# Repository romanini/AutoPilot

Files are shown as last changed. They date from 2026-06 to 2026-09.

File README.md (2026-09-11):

# AutoPilot Project

A DIY autopilot that steers a wheel-driven sailboat.  It holds either a
**compass heading** or **navigates to a GPS waypoint**, driving a motor on the
steering wheel. Two standalone sensors — rudder angle and masthead wind — report
to it over the same Wi-Fi network.

## System overview

Every unit joins one Wi-Fi network, `SoberPilot` (`10.20.1.x`), which the
controller itself hosts:

| Part | Hardware | Role |
|---|---|---|
| **Controller** | Arduino Nano ESP32 | The brain: reads IMU + GPS, runs PID steering, drives the motor, hosts the `SoberPilot` access point, broadcasts telemetry |
| **Display unit(s)** | Arduino Nano ESP32 + 320×480 TFT | Cockpit head unit: live autopilot state on a colour LCD, five buttons for mode/heading control. Panel is an HX8357 module or a ST7365P, detected at boot |
| **Rudder sensor** | Arduino Nano ESP32 + AS5600L | Standalone board at the quadrant: reports rudder angle, which a wheel-steered boat has no other way to know |
| **Wind sensor** | Arduino Nano ESP32 + AS5600L, Hall switch, DS18B20 | Standalone masthead unit: apparent wind angle and speed, plus air temperature |
| **Wind display** | Arduino Nano ESP32 + 320×480 TFT, portrait | Second head unit on the cockpit bulkhead: the masthead wind as an analogue dial, apparent and true. Listen-only — no buttons, transmits nothing |
| **Navigator** | Raspberry Pi 5 (8 GB) + OpenCPN | Chart plotter: GPS, AIS and vector charts; the host for the plugin below. See [`navigator/README.md`](navigator/README.md) for the hardware alternatives that were evaluated |
| **OpenCPN plugin** | `autopilot_pi` (C++/wxWidgets) | Software display unit inside OpenCPN: mirrors the TFT panel on screen, sends commands, pushes active waypoints to the controller |

How the units talk to each other

The controller is the only unit anything else talks to — the sensors, the
display and the navigator never talk to each other.

## The protocol

All communication uses plain-text UDP datagrams framed `~…$`, on four pairs of
ports:

- **Telemetry** `~APDAT,…$` — controller → everyone, **broadcast UDP 8888**, ~1 Hz.
  39 fields: date/time, GPS fix, nav_enabled, mode, waypoint, heading, pitch,
  roll, stability, bearing, speed, distance, course, location, the rudder angle
  with its health flag, and the masthead wind — apparent angle/speed, the
  controller-derived true angle/speed, and air temperature, each with its own
  health flag. `controller/publish.ino` is the wire format; `AutoPilot::parse`
  is the reader.
- **Commands** `~APCMD,<cmd>$` — display or navigator → controller, **unicast
  UDP 8889**: `m1`/`m2` (mode), `n0`/`n1` (nav enable), `a±N.NN` (heading
  adjust), `w<lat>,<lon>` (set waypoint), `X` (follow stopped), `t0`/`t1`/`t2`
  (PID auto-tune abort/arm/start), `z` (centre the rudder — relayed on to the
  rudder board).
- **Rudder sensor** — `~APRUD,<angle>,<magnet_ok>$` sensor → controller on
  **UDP 8890**; `~APCMD,z$` back on **UDP 8891**.
- **Wind sensor** — `~APWND,<direction>,<speed_kn>,…$` sensor → controller on
  **UDP 8892**; `~APCMD,v$` (vane zero) and `~APCMD,k<slope>,<offset>$`
  (speed calibration) back on **UDP 8893**.
- **Reset** `~RESET,1$`.

`mode`: `0` = off, `1` = compass-hold, `2` = waypoint-navigate.

Telemetry is broadcast, so any number of displays and plugins can listen at
once; everything else is unicast. Both sensor calibrations are runtime commands
persisted in NVS, so a unit that is already up a mast never has to be reflashed.
[`firmware/Arduino/README.md`](firmware/Arduino/README.md) is the authoritative protocol
reference.

## Directories

Five top-level directories, split by where the thing runs or what it is made of.
Each has its own README with the detail — start there rather than here.

| Directory | What's in it |
|---|---|
| [`firmware/`](firmware/README.md) | Everything that runs on a microcontroller: the five Arduino sketches, the Garmin emulator and NMEA test harness, and the offline PID and wind-dial rendering experiments |
| [`navigator/`](navigator/README.md) | Everything that runs on the Raspberry Pi 5: its setup, the config files as deployed, and the `autopilot_pi` OpenCPN plugin |
| [`circuit/`](circuit/README.md) | EasyEDA exports for the seven PCBs, and how they stack into the four units |
| [`cad/`](cad/README.md) | Enclosures, one directory per unit |
| [`assets/`](assets/) | Images and diagrams used in documentation — no README, just files |

## Quick-start by component

**Firmware** — see [`firmware/Arduino/README.md`](firmware/Arduino/README.md) for pinouts,
libraries, build, and upload commands. All five sketches (controller, display,
rudder, wind, wind-display) need a matching `arduino_secrets.h`.

**Navigator** — see [`navigator/README.md`](navigator/README.md) for the
Raspberry Pi 5 build: Ubuntu 24.04, NVMe boot, Wi-Fi onto SoberPilot, and the
OpenCPN Flatpak install.

**OpenCPN plugin** — see
[`navigator/opencpn_plugin/autopilot_pi/README.md`](navigator/opencpn_plugin/autopilot_pi/README.md)
for the panel layout, build command, and send-waypoint workflow.

**Boards** — see [`circuit/README.md`](circuit/README.md) for the seven PCBs,
how they stack into the four units, and the Gerbers to send to a board house.

**Enclosures** — see [`cad/`](cad/). The [wind sensor](cad/wind/README.md) is
built and printable; the other three are placeholders.

**Testing without a boat** — [`firmware/emulator/`](firmware/emulator/README.md) stands in for the
Garmin GPSMAP 276c on the controller's NMEA UART, and carries the test harness
for the wire contract.

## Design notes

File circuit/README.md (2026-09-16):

# AutoPilot circuit boards

This directory holds the **EasyEDA exports** for every custom PCB in the
AutoPilot project. There are seven boards, one directory each:

```
circuit/                                                                     unit
├── Controller/                 The Autopilot brain          rev 2.1  ─┐
├── Controller-12-volt-power/   power + NMEA interconnect    rev 1.0  ─┘─ controller
├── Display/                    cockpit head-unit mainboard  rev 2.2  ─┐
├── Display-Button/             buttons + TFT pass-through   rev 1.0   ├─ display
├── Display-LCD/                ST7365P panel carrier        rev 1.0  ─┘
├── Sensor-Rudder/              Inticator of rudder postion  rev 1.0  ─── rudder sensor
├── Sensor-Wind/                Wind speed and direction     rev 1.0  ─── wind sensor
└── tools/                      export automation (see tools/README.md)
```

These PCBs implement the hardware described in [`../firmware/Arduino/README.md`](../firmware/Arduino/README.md):
the **controller** reads the sensors and drives the steering motor, the
**display** is the cockpit head unit with an LCD and buttons, and the **rudder**
and **wind** sensors are standalone boards that report to the controller. All
four units are built around the **Arduino Nano ESP32** and talk to each other
over the `SoberPilot` Wi-Fi network.

## Seven boards, four enclosures

The directories are flat — one per EasyEDA project — but the boards are not
independent. They stack up into **four physical units**, and only the four
units talk to each other, over Wi-Fi:

| Unit | Boards inside it | Enclosure | Interconnect | Power |
|---|---|---|---|---|
| **Controller** | [`Controller`](Controller/README.md) + [`Controller-12-volt-power`](Controller-12-volt-power/README.md) | [`cad/controller/`](../cad/controller/README.md) | 2×10 ribbon, board to board | 12 V into the power board, fused there |
| **Display** (cockpit head unit) | [`Display`](Display/README.md) + [`Display-Button`](Display-Button/README.md) + [`Display-LCD`](Display-LCD/README.md) | [`cad/display/`](../cad/display/README.md) | 2×10 ribbon mainboard→button board, then 8-pin JST-XH button board→panel | 12 V, or its own LiPo when 12 V is absent |
| **Rudder sensor** | [`Sensor-Rudder`](Sensor-Rudder/README.md) | [`cad/rudder/`](../cad/rudder/README.md) | — (single board) | 12 V into its own terminal block |
| **Wind sensor** | [`Sensor-Wind`](Sensor-Wind/README.md) | [`cad/wind/`](../cad/wind/README.md) | — (single board) | 12 V from the masthead light circuit |

So the two controller boards share one case, the three display boards share
another, and each sensor is a sealed one-board unit with nothing running to it
but a 12 V pair — which is the point of putting them on Wi-Fi rather than
wiring them back to the controller. [`Display-LCD`](Display-LCD/README.md) is
optional: it is only fitted when the ST7365P panel is used instead of an HX8357
module.

The case each unit lives in is designed in [`../cad/`](../cad/) — one directory
per unit, linked in the table above. Only the
[wind sensor](../cad/wind/README.md) is built; the other three are placeholders
that so far only record the constraints.

## What's in each folder

Every board is exported from EasyEDA with the same 13 files, produced by
[`tools/`](tools/README.md) (`npm run export`) rather than by hand. Filenames
follow `<SCH|PCB>_<board>_<type>.<ext>`. The `README.md` alongside them is the
one hand-written file in each directory; the exporter only ever adds, so a
re-export leaves it alone:

| File | What it is |
|---|---|
| `SCH_*_PNG.png` / `SCH_*_SVG.svg` | Schematic, as a quick-look image |
| `SCH_*_EasyEDA.json` | Editable schematic source (open in EasyEDA) |
| `SCH_*_Altium.schdoc` | Schematic exported for Altium Designer |
| `PCB_*_PNG.png` / `PCB_*_SVG.svg` | PCB layout, top view |
| `PCB_*_EasyEDA.json` | Editable PCB source (open in EasyEDA) |
| `PCB_*_Gerber.zip` | **Gerbers — send this to the board house to fabricate** |
| `PCB_*_DXF.dxf` | Board outline / layers as DXF (CAD, enclosures) |
| `PCB_*_OBJ.zip` | 3D model of the assembled board (.obj) |
| `PCB_*_PhotoView-Top.svg` / `*-Bottom.svg` | Photo-realistic render of the populated board |
| `PCB_*_Autorouter.dsn` | Specctra DSN for external auto-routing |

To fabricate a board, upload its `*_Gerber.zip` to a PCB house (JLCPCB, PCBWay,
OSH Park, etc.). To edit a board, import the `*_EasyEDA.json` files back into
EasyEDA. To re-export everything after a change, see
[`tools/README.md`](tools/README.md).

---

## The seven boards

Each board directory has its own README with the schematic, the PCB image, a
component table and the design notes for that board:

| # | Board | EasyEDA project | What it is |
|---|---|---|---|
| 1 | [`Controller/`](Controller/README.md) | `SM AP Controller` rev 2.1 | The autopilot brain — Nano ESP32, BNO085 IMU, GPS, CD4010 serial buffers, motor and kill-switch headers |
| 2 | [`Controller-12-volt-power/`](Controller-12-volt-power/README.md) | `SM AP Power` rev 1.0 | Passive power and NMEA interconnect — 12 V entry, Garmin feed, USB-C, two fuses, ribbon to the controller |
| 3 | [`Display/`](Display/README.md) | `SM AP Display` rev 2.2 | Head-unit mainboard — Nano ESP32, LiPo + TP5100 charger, TPS61023 boost, voltage dividers |
| 4 | [`Display-Button/`](Display-Button/README.md) | `SM Button board V2` rev 1.0 | Five cockpit buttons, illuminated power switch, SPI pass-through to the panel |
| 5 | [`Display-LCD/`](Display-LCD/README.md) | `AutoPilot LCD Carrier` v1.0 | Optional ST7365P panel carrier — 3V3 LDO, backlight FET, 40-pin FPC |
| 6 | [`Sensor-Rudder/`](Sensor-Rudder/README.md) | `SM AP Rudder Sensor` rev 1.0 | Rudder angle — Nano ESP32 + AS5600L magnetic encoder, 12 V in |
| 7 | [`Sensor-Wind/`](Sensor-Wind/README.md) | `SM AP Wind Sensor` rev 1.0 | Masthead unit — AS5600L vane, SS40AF Hall cup sensor, DS18B20 air temperature |

---

## How the boards fit together

The units talk to each other over Wi-Fi and nothing else. The controller hosts
the **SoberPilot** access point; the display, the two sensors and the navigator
(a Raspberry Pi 5 running OpenCPN) all join it as stations. Each sensor reports
on its own port and is commanded back on the next one up, while the display and
the navigator receive the telemetry broadcast and send commands to the
controller.

How the boards fit together

What is inside the controller and the display units follows below.

### Inside the controller unit

Everything from the outside world lands on the **12-volt-power** board, which
fuses it and hands it to the **controller** over one ribbon. The controller's
only outgoing connection is the motor header — the motor driver itself is a
bought part and is not one of these boards.

Inside the controller unit

### Inside the display unit

Note the power path: **12 V and USB charge the battery and nothing else.** The
LiPo is the only thing that actually powers the display board, which then feeds
the button board and the panel.

Inside the display unit

For the firmware that runs on these boards, the pin assignments, and build
instructions, see [`../firmware/Arduino/README.md`](../firmware/Arduino/README.md). For the
overall system architecture and the UDP protocol, see the
[top-level README](../README.md). For re-exporting these files from EasyEDA,
see [`tools/README.md`](tools/README.md).

---

## Review notes (open items)

From a pass over all seven schematics, checked against the firmware. Nothing
here is a short or a crossed power rail — no net on any board carries two
different rail labels. These are the things to settle before the new boards go
out, roughly in order of how much they hurt.

**Board fix — confirmed**

1. **USB `D+`/`D−` are crossed on the display mainboard.** The USB connector's
   `D−` (pin 4) goes to the CH224K's `DP` *and* to the "Arduino USB" header's
   `D+`; `D+` (pin 5) goes to `DM` and to `D−`. The controller board wires the
   same 3-pin header straight through, so the two boards contradict each other.
   Confirmed as a genuine error — being fixed in EasyEDA; this export still has
   it. Re-export once corrected.

**Firmware TODO — next revision, once the new hardware is in hand**

Deferred deliberately: a code change that wants the real board on the bench,
not a schematic change.

2. ~~**Display voltage dividers disagree with the firmware.**~~ **Fixed.**
   `display/volt_meter.ino` now uses this board's ratios, 0.1525 (10 k/1.8 k)
   on v-in and 0.5455 (10 k/12 k) on the battery, with correction factors
   calibrated against a multimeter on 2026-09-13 (1.00487 battery, 1.01333
   v-in). Closed.
3. **Nothing ever drives the LCD carrier's backlight.** `BL_PWM` runs from the
   mainboard's `D8` through the ribbon and the button board to the carrier's
   FET gate, and no code in `display/` touches `D8`. R5's 100 kΩ holds the gate
   low, so the panel lights up black. HX8357 modules hard-wire their backlight,
   which is why this has not bitten yet.

**Marginal / out of spec**

4. **The Transmit Buffer is a level shifter pointed the wrong way.** U5 has
   `VCC` = `VDD` = 5 V with 3.3 V ESP32 inputs; at `VDD` = 5 V the CD4010B needs
   `VIH` ≥ 3.5 V. It typically works at room temperature but is not guaranteed.
   The CD4010 only converts *down* — U2 (Receive) is wired correctly at
   `VDD` = 5 V, `VCC` = 3.3 V. A 74LVC part or a real NMEA driver is the fix.
5. **Indicator LEDs with no ballast.** The controller's kill-switch LED sits
   between +5 V and a saturated 2N2222 (the 1 kΩ is in the *base*), and the
   display's switch LED runs straight to the TP5100's `LED+`/`STDBY`. Both rely
   on the switch having an internal resistor.
6. **Power-switch polarity.** CN2's contacts bridge GND and the TPS61023's `EN`,
   which Adafruit's MiniBoost pulls high — so closing the switch turns the
   display *off*. Needs a normally-closed switch, or `EN` pulled down and
   switched to 5 V.

**Verify against datasheets**

7. **LCD backlight drive.** Three cathodes, each through 51 Ω, anodes on +5 V.
   That only works if each string is a single ~3.2 V LED; series strings cannot
   run from 5 V and would need a boost driver. Biggest unknown on the carrier.
8. **CH224K `CFG1` = 56 kΩ** selects a PD voltage that then lands on the
   TP5100's input through D2. The TP5100 is a 5–18 V part, so confirm both the
   CFG table and that more than 5 V is wanted here at all.
9. **USB-C `CC`.** The controller path terminates one `CC` pin with a single
   5.1 kΩ; if the receptacle brings out `CC1` and `CC2`, the cable will only
   work one way up. (The display is fine — the CH224K terminates both.)

**Housekeeping**

10. Ribbon conductors driven at one end and unconnected at the other:
    controller↔power pins 7 (USB VBUS) and 8 (Garmin alarm) into the controller,
    14 (Garmin 12 V) likewise, and 17–20 (motor rails) out of it. Running motor
    drive down the same ribbon as Garmin serial is also an EMI risk.
11. Neither Nano gets USB `VBUS` — both "Arduino USB" headers carry `D+`/`D−`
    and ground only.
12. No decoupling anywhere on the controller (neither CD4010, nor the 5 V rail);
    the display has only the CH224K's 1 µF. No reverse-polarity or transient
    protection on any 12 V input, and the masthead board has no fuse; the
    1N5817s are 20 V parts on a boat rail.
13. The GPS's `VBat` is unconnected, so it cold-starts every power-up.
14. `controller/garmin.ino`'s pin comment swaps the names of the Receive and
    Transmit buffers. The pin numbers are right.
15. The Display schematic's title block says "Sheet 1/3", but the project
    exports as a single sheet.

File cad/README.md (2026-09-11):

# Enclosures

The case each AutoPilot unit lives in, one directory per unit. Only the wind
sensor is designed and printable; the other three record what their enclosure
has to do, ready for someone to draw it.

| Unit | Enclosure | Status | Boards inside |
|---|---|---|---|
| Wind sensor | [`wind/`](wind/README.md) | **Built** — FreeCAD sources and a full assembly guide | [`circuit/Sensor-Wind/`](../circuit/Sensor-Wind/README.md) |
| Controller | [`controller/`](controller/README.md) | Placeholder | [`circuit/Controller/`](../circuit/Controller/README.md) + [`circuit/Controller-12-volt-power/`](../circuit/Controller-12-volt-power/README.md) |
| Display | [`display/`](display/README.md) | Placeholder | [`circuit/Display/`](../circuit/Display/README.md) + [`circuit/Display-Button/`](../circuit/Display-Button/README.md) + [`circuit/Display-LCD/`](../circuit/Display-LCD/README.md) |
| Rudder sensor | [`rudder/`](rudder/README.md) | Placeholder | [`circuit/Sensor-Rudder/`](../circuit/Sensor-Rudder/README.md) |

## Layout convention

Each unit directory follows the same shape:

```
<unit>/
├── README.md     what the enclosure has to do, and what goes inside
└── *.FCStd       FreeCAD documents — the editable source
```

**FreeCAD documents are the only source of truth. No STLs are kept in the
repo** — export a mesh from the `.FCStd` when you are about to print, and leave
it out of git. Anything checked in would be a stale copy of a model that has
moved on.

The [wind sensor](wind/README.md) is the worked example: it adds an
`Assembly.md` with the step-by-step build, the shopping list, and the print
settings.

## What every one of these cases has in common

- **Plastic, not metal.** Every unit is on the `SoberPilot` Wi-Fi — the
  controller hosts the network and the other three join it as stations — so no
  case may act as a shield. The controller's is the critical one: everything
  else reaches it through those walls.
- **PETG or ASA, in a light colour.** Not PLA, which creeps and sags in the sun.
  Dark filament heats enough at a masthead or in a cockpit to go soft.
- **Sealed, with the cable entry as the weak point.** These live at a masthead,
  in a cockpit and in a quadrant locker. Only the controller's box is anywhere
  dry, and a bilge is never guaranteed dry either.
- **No iron near a magnet or a compass.** The controller carries the IMU that
  *is* the boat's heading reference, and both sensors read a magnet through a
  small air gap.

The board dimensions, connector positions and mounting holes all come from the
EasyEDA exports in [`circuit/`](../circuit/README.md) — each board directory
ships a DXF and a 3D model of the assembled board for exactly this purpose.

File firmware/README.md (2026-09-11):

# Firmware

Everything that runs on a microcontroller, plus the tooling used to test it off
the boat. Five Arduino Nano ESP32 units, one sketch each, all talking over the
`SoberPilot` Wi-Fi network — see the [top-level README](../README.md) for the
protocol and how the units fit together.

## What is in here

| Directory | What it is |
|---|---|
| [`Arduino/`](Arduino/README.md) | All the sketches, the vendored libraries and the upload tooling. **Its README is the authoritative build reference** — pinouts, library table, `arduino-cli` commands |
| [`emulator/`](emulator/README.md) | A Python stand-in for the Garmin GPSMAP 276c on the controller's NMEA UART, plus the authoritative implementation of the NMEA wire contract and its tests |
| `experiments/pid/` | Offline PID tuning — `pid_test.py` replays logged runs and plots them with matplotlib |
| [`experiments/wind-display-render/`](experiments/wind-display-render/README.md) | Compiles the wind display's real drawing code on the Mac and renders PNGs of every screen state — how its layout is checked, and how the incremental repaint is proven leak-free, without hardware |

## The five units

Each sketch is one physical unit. The board it runs on and the case it lives in
are documented alongside it:

| Sketch | Unit | Board | Enclosure |
|---|---|---|---|
| [`Arduino/controller/`](Arduino/controller/) | The brain — IMU, GPS, PID steering, motor drive, and the Wi-Fi access point | [`circuit/Controller/`](../circuit/Controller/README.md) | [`cad/controller/`](../cad/controller/README.md) |
| [`Arduino/display/`](Arduino/display/) | Cockpit head unit — TFT and five buttons | [`circuit/Display/`](../circuit/Display/README.md) | [`cad/display/`](../cad/display/README.md) |
| [`Arduino/rudder/`](Arduino/rudder/) | Rudder angle sensor at the quadrant | [`circuit/Sensor-Rudder/`](../circuit/Sensor-Rudder/README.md) | [`cad/rudder/`](../cad/rudder/README.md) |
| [`Arduino/wind/`](Arduino/wind/) | Masthead wind sensor — angle, speed, air temperature | [`circuit/Sensor-Wind/`](../circuit/Sensor-Wind/README.md) | [`cad/wind/`](../cad/wind/README.md) |
| [`Arduino/wind-display/`](Arduino/wind-display/) | Cockpit wind display — portrait analogue wind dial, listen-only | [`circuit/Display/`](../circuit/Display/README.md) (same boards as the head unit) | — |

`Arduino/` also holds single-purpose sketches that are not units: `garmin/` for
bringing up the Garmin NMEA input, and `panel_detect/`, `panel_probe/` and
`st7365_bringup/` for identifying and driving the display panel.

## Before you build

Every sketch needs an `arduino_secrets.h` with the Wi-Fi password, and **it must
match across the controller, every display (including the wind display), and
both sensors** — a mismatch
looks like a unit that boots fine and never appears on the network. Copy the
example alongside each sketch to get started.

Libraries are declared in each sketch's `sketch.yaml` and in the table in
[`Arduino/README.md`](Arduino/README.md); when adding an `#include`, update
those rather than vendoring the library.

## Testing without a boat

[`emulator/`](emulator/README.md) drives the controller's Garmin UART over a
USB-serial tap, so route and waypoint handling can be exercised at a desk. It is
a serial device rather than an IP endpoint, and it is the reference
implementation of the NMEA framing the controller parses — if the two ever
disagree, the emulator's tests are the tie-breaker.

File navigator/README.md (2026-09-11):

# Navigator

The navigation computer runs Ubuntu with OpenCPN (Flatpak) and the `autopilot_pi` plugin.
Version depends on hardware: 22.04 on the OrangePi and RPi 4, 24.04 on the RPi 5 (22.04
predates Pi 5 hardware support). Hardware options evaluated so far:

| Hardware | Power @ 12 V | OpenGL | Notes |
|---|---|---|---|
| OrangePi Zero 2W | ~2.4-3.3 W (0.2-0.28 A) | Off — GPU driver unreliable | Development unit |
| Raspberry Pi 4 Model B (8 GB) | ~3.0-6.0W (0.25-0.5 A) | On — VideoCore VI (vc4-kms-v3d) works | Better chart rendering |
| Raspberry Pi 5 (8 GB) | 4.5W | On — VideoCore VII, faster than RPi 4 | SD card + NVMe (see below) |

OpenGL makes chart panning and zooming significantly faster. The RPi 4 and RPi 5 support it;
the OrangePi does not. Measure actual power draw with a meter before choosing which to install
on the boat.

**RPi 5 boot media:** the Pi 5 uses both an SD card and an NVMe drive (attached via a PCIe
M.2 HAT). NVMe is the primary boot device — faster and no SD wear-out concerns for an
appliance that's powered on/off with the boat. The SD card stays installed as a fallback: if
the NVMe drive ever fails or is removed, the bootloader falls back to booting it. Both cards
get a full, independent Ubuntu install — see [Part 1](#part-1--flash-the-boot-media-on-your-mac)
and [Enable NVMe boot](#raspberry-pi-5--enable-nvme-boot) below.

---

## SD card backup and restore

The navigator setup is not distributed as a disk image — it is too large for Git.
To set up a fresh card, follow the from-scratch setup below. Use the commands here
to back up an existing working card or restore from a backup.

**Two things make `dd` fast on macOS:**
- Use `/dev/rdisk3` not `/dev/disk3` — the `r` prefix (raw device) bypasses the buffer cache and is ~10× faster.
- Use `bs=4m` for large block transfers instead of the default 512-byte blocks.

Pipe through `gzip` to compress the output; this cuts file size roughly in half
and is usually faster overall because writing less to disk beats the CPU cost of
compression. Hit **Ctrl+T** at any time to print progress.

### Backup: SD card → compressed file

1. Find your SD card device:
   ```bash
   diskutil list
   ```
2. Unmount it (replace `disk3` with your actual device):
   ```bash
   diskutil unmountDisk /dev/disk3
   ```
3. Copy and compress (use the filename for your hardware/media):
   ```bash
   # OrangePi Zero 2W
   sudo dd if=/dev/rdisk3 bs=4m | gzip > navigator-OrangePiZero2W-$(date +%Y-%m-%d).img.gz
   # Raspberry Pi 4 Model B
   sudo dd if=/dev/rdisk3 bs=4m | gzip > navigator-RaspberryPi4ModelB-$(date +%Y-%m-%d).img.gz
   # Raspberry Pi 5 — SD card (fallback boot)
   sudo dd if=/dev/rdisk3 bs=4m | gzip > navigator-RaspberryPi5-SD-$(date +%Y-%m-%d).img.gz
   # Raspberry Pi 5 — NVMe (primary boot; remove from the M.2 HAT and attach via a
   # USB-to-M.2 NVMe enclosure — the device node will differ, check `diskutil list`)
   sudo dd if=/dev/rdisk4 bs=4m | gzip > navigator-RaspberryPi5-NVMe-$(date +%Y-%m-%d).img.gz
   ```

### Restore: compressed file → SD card

1. Unmount the card:
   ```bash
   diskutil unmountDisk /dev/disk3
   ```
2. Decompress and write:
   ```bash
   # OrangePi Zero 2W
   gunzip -c navigator-OrangePiZero2W-YYYY-MM-DD.img.gz | sudo dd of=/dev/rdisk3 bs=4m
   # Raspberry Pi 4 Model B
   gunzip -c navigator-RaspberryPi4ModelB-YYYY-MM-DD.img.gz | sudo dd of=/dev/rdisk3 bs=4m
   # Raspberry Pi 5 — SD card
   gunzip -c navigator-RaspberryPi5-SD-YYYY-MM-DD.img.gz | sudo dd of=/dev/rdisk3 bs=4m
   # Raspberry Pi 5 — NVMe (via USB-to-M.2 enclosure; check `diskutil list` for the device node)
   gunzip -c navigator-RaspberryPi5-NVMe-YYYY-MM-DD.img.gz | sudo dd of=/dev/rdisk4 bs=4m
   ```

---

## From-scratch setup

### Part 1 — Flash the boot media (on your Mac)

#### OrangePi Zero 2W

1. Go to the OrangePi Zero 2W product page at orangepi.org → **Resources** and download
   the **Ubuntu Jammy (22.04)** image.
2. Decompress the `.xz` archive:
   ```bash
   xz -d Orangepi*.img.xz
   ```
3. Unmount the SD card and flash it directly (no gzip since the image is already unpacked):
   ```bash
   diskutil unmountDisk /dev/disk2
   sudo dd if=Orangepi*.img of=/dev/rdisk2 bs=4m
   ```

#### Raspberry Pi 4 Model B

1. Install [Raspberry Pi Imager](https://www.raspberrypi.com/software/) on your Mac.
2. Open Imager → **Choose OS** → **Other general-purpose OS** → **Ubuntu** →
   **Ubuntu Server 22.04 LTS (64-bit)**.
3. Click the ⚙ settings icon and configure:
   - **Hostname:** `navigator`
   - **Username:** `navigator`
   - **Password:** your choice
   - **Enable SSH:** yes
4. **Choose Storage** → select your SD card → **Write**.

The root filesystem expands to fill the card automatically on first boot — no manual step needed.

#### Raspberry Pi 5 (SD card + NVMe)

Flash **both** cards now, before the Pi 5 ever powers on — it's easiest to do them
back-to-back on the Mac while Imager is already open.

1. **SD card first** (this becomes the fallback boot media): same steps as RPi 4 above, except
   choose **Ubuntu Server 24.04 LTS (64-bit)** and use hostname `navigator`. Set the same
   username/password/SSH settings you'll use on the NVMe drive.
2. **NVMe drive** (this becomes the primary boot media): connect the NVMe drive to your Mac
   via a USB-to-M.2 NVMe enclosure/adapter (it isn't readable directly — the Pi 5's M.2 HAT
   is the only thing that talks to it over PCIe). In Imager, repeat the same OS choice
   (**Ubuntu Server 24.04 LTS (64-bit)**) and the same ⚙ settings (hostname `navigator`,
   same username/password, SSH enabled) → **Choose Storage** → select the NVMe device (not
   the SD card!) → **Write**.
3. Don't set `BOOT_ORDER` yet — NVMe boot has to be enabled from the EEPROM bootloader while
   running from the SD card, so put the SD card in and boot that first. The NVMe drive itself
   can go into the M.2 HAT whenever it's convenient: the EEPROM only decides what the
   *bootloader* tries, so an installed drive stays inert until
   [Enable NVMe boot](#raspberry-pi-5--enable-nvme-boot) after Part 2 below.

**Don't have the NVMe drive yet?** Skip step 2 above and do everything through Post-setup on
the SD card alone — see
[Set up on the SD card now, clone to NVMe later](#set-up-on-the-sd-card-now-clone-to-nvme-later)
below for how to catch the NVMe drive up once it arrives.

#### Set up on the SD card now, clone to NVMe later

You don't need the NVMe drive in hand to get started — flash and set up the SD card only
(steps above minus step 2), work all the way through Part 2 → Post-setup on it, and validate
everything works. When the NVMe drive arrives:

1. **Back up the SD card first.** Shut down, remove the SD card, and image it on your Mac using
   the [backup commands](#backup-sd-card--compressed-file) (the
   `navigator-RaspberryPi5-SD-...img.gz` line). This is the only rollback if the clone goes
   wrong. Re-insert the SD card and boot the Pi 5 normally again.

2. **Install the NVMe drive in the M.2 HAT** — no USB-to-M.2 enclosure needed. `BOOT_ORDER`
   still points at the SD card, so the Pi keeps booting from it while the NVMe shows up as an
   ordinary block device you can clone onto locally. Boot from the SD card and confirm:

   ```bash
   lsblk -o NAME,SIZE,TYPE,FSTYPE,LABEL,LOG-SEC,MOUNTPOINTS
   ```

   Check three things: the drive is `nvme0n1` at the expected size, the live system is on
   `mmcblk0`, and `LOG-SEC` reads `512`. A namespace formatted 4Kn needs a different approach —
   the SD image's partition table uses 512-byte offsets, so a straight `dd` clone onto it would
   produce a broken layout.

   If `nvme0n1` doesn't appear at all, the PCIe port isn't enabled. The official Raspberry Pi
   M.2 HAT+ enables it automatically via its HAT EEPROM; third-party boards (Pimoroni NVMe Base,
   Geekworm, Waveshare) generally don't. Add `dtparam=pciex1` under `[all]` in
   `/boot/firmware/config.txt` and reboot.

3. **Wipe the drive if it has ever been used for anything else** (skip only for a genuinely
   factory-fresh drive — and copy off anything you still want first, all of it is destroyed
   here).

   This is not just tidiness. A drive formatted by macOS or Windows carries a **GPT**: a primary
   header at LBA 1 and a backup header in the *last sector of the drive*. Cloning a 32 GB SD
   image onto a 1 TB NVMe overwrites the primary but leaves the backup untouched, so the disk
   ends up carrying both a valid MBR and a valid backup GPT. `parted` and `gdisk` then report
   the GPT as corrupt and offer to rebuild it from the backup — which discards the MBR you just
   cloned — and `sfdisk`/`growpart` in step 5 can auto-detect the wrong label type entirely.

   ```bash
   lsblk -no MOUNTPOINTS /dev/nvme0n1   # unmount anything listed before continuing
   sudo blkdiscard -f /dev/nvme0n1      # TRIM the whole drive: seconds, vs hours to zero-fill
   sudo wipefs -a /dev/nvme0n1          # this is what kills the backup GPT
   sudo partprobe /dev/nvme0n1
   ```

   `blkdiscard` alone is not enough — not every controller guarantees discarded blocks read back
   as zeros, so `wipefs` removes the signatures explicitly rather than assuming.

4. **Quiesce the system and clone.** Dropping to `multi-user.target` stops the desktop and
   OpenCPN writing during the copy:

   ```bash
   sudo systemctl isolate multi-user.target
   sudo dd if=/dev/mmcblk0 of=/dev/nvme0n1 bs=4M status=progress conv=fsync
   sudo partprobe /dev/nvme0n1
   ```

   Cloning a mounted root filesystem means files written during the copy (in practice, logs) can
   land inconsistent; the `e2fsck` in step 5b resolves the metadata side, and this is what
   `rpi-clone` and similar tools do anyway. To write the pristine image instead, put the
   `.img.gz` from step 1 on a USB stick and
   `gunzip -c /media/…/navigator-RaspberryPi5-SD-*.img.gz | sudo dd of=/dev/nvme0n1 bs=4M status=progress`.

5. **Give the clone its own identity, and grow it into the drive.** A straight clone leaves the
   NVMe with the same MBR disk signature (and therefore `PARTUUID`s), the same filesystem UUIDs,
   **the same filesystem labels**, the same machine-id and the same SSH host keys as the SD card.
   With both physically installed at once — which is the whole point of the fallback design —
   that's not cosmetic: the kernel, udev and blkid can't reliably tell the two apart and may
   resolve to the wrong one.

   **The labels matter most, because this image boots by label.** `boot/firmware/cmdline.txt` in
   this repo has `root=LABEL=writable`, and `/etc/fstab` mounts `LABEL=writable` and
   `LABEL=system-boot`. Leave the clone's labels alone and `root=LABEL=writable` is ambiguous with
   both media installed — you can end up with a Pi that boots the NVMe's firmware but runs the SD
   card's filesystem. Relabelling the NVMe fixes both directions at once: the SD's `writable` then
   matches only the SD, and the NVMe's `writable-nvme` matches only the NVMe.

   Do all of this with the NVMe unmounted, in this order (adjust partition numbers if `lsblk`
   showed something other than `p1`/`p2`):

   a. **New MBR disk signature** — this is what each partition's `PARTUUID` is derived from
      (`<disk-id>-<partition-number>`):
      ```bash
      sudo sfdisk --disk-id /dev/nvme0n1 0x$(openssl rand -hex 4)
      sudo partprobe /dev/nvme0n1
      ```
   b. **Grow the root partition to fill the drive.** Without this a clone of a 32 GB card onto a
      1 TB drive is still a 32 GB system — cloud-init's first-boot auto-resize already ran on the
      SD card and won't run again. `growpart` comes from `cloud-guest-utils`:
      ```bash
      sudo growpart /dev/nvme0n1 2
      sudo e2fsck -f /dev/nvme0n1p2
      sudo resize2fs /dev/nvme0n1p2
      ```
   c. **New root filesystem UUID:**
      ```bash
      sudo tune2fs -U random /dev/nvme0n1p2
      ```
   d. **New labels** — see above, this is the one that decides whether it boots the right root:
      ```bash
      sudo e2label /dev/nvme0n1p2 writable-nvme
      sudo fatlabel /dev/nvme0n1p1 SYSTEM-NVME
      ```
      The FAT label must be uppercase and at most 11 characters — dosfstools 4.2 refuses lowercase
      labels, and `SYSTEM-NVME` is exactly 11. ext4 allows 16, so `writable-nvme` fits.
   e. **New FAT32 volume ID.** `dosfstools` has no in-place command for this, so patch the 4-byte
      `BS_VolID` field directly at its fixed offset (67) in the boot sector instead of
      reformatting:
      ```bash
      sudo dd if=/dev/urandom of=/dev/nvme0n1p1 bs=1 count=4 seek=67 conv=notrunc
      ```
   f. **Confirm the two media now look nothing alike:**
      ```bash
      sudo blkid /dev/mmcblk0p1 /dev/mmcblk0p2 /dev/nvme0n1p1 /dev/nvme0n1p2
      ```
      All four labels and all four UUIDs should be distinct before you go any further.

6. **Point the clone's boot config at its own labels.** Both `sed` patterns below are idempotent —
   the replacement text no longer matches the pattern, so re-running them is harmless.

   ```bash
   sudo mkdir -p /mnt/nvme-boot /mnt/nvme-root
   sudo mount /dev/nvme0n1p1 /mnt/nvme-boot
   sudo mount /dev/nvme0n1p2 /mnt/nvme-root

   sudo sed -i 's|root=LABEL=writable |root=LABEL=writable-nvme |' /mnt/nvme-boot/cmdline.txt
   sudo sed -i 's|LABEL=writable\([[:space:]]\)|LABEL=writable-nvme\1|; s|LABEL=system-boot\([[:space:]]\)|LABEL=SYSTEM-NVME\1|' /mnt/nvme-root/etc/fstab

   # Read both back — this is the step that decides whether it boots at all
   cat /mnt/nvme-boot/cmdline.txt /mnt/nvme-root/etc/fstab
   ```

   Then **machine-id and SSH host keys** — not partition-related, but the same "identical clone"
   problem: both media would otherwise claim the same machine identity on the network.

   ```bash
   sudo rm /mnt/nvme-root/etc/machine-id
   sudo systemd-machine-id-setup --root=/mnt/nvme-root
   sudo rm /mnt/nvme-root/etc/ssh/ssh_host_*
   sudo ssh-keygen -A -f /mnt/nvme-root

   # Normally a symlink to /etc/machine-id; if it's a real file, copy the new one over it
   ls -l /mnt/nvme-root/var/lib/dbus/machine-id

   sudo umount /mnt/nvme-boot /mnt/nvme-root
   ```

   Expect two harmless side effects on first NVMe boot: your Mac refuses to connect until you run
   `ssh-keygen -R navigator.local`, and the Pi may take a different DHCP lease because the
   machine-id changed.

7. Pick up at step 2 of [Enable NVMe boot](#raspberry-pi-5--enable-nvme-boot) below — the drive is
   already installed, so all that's left is the EEPROM update, `BOOT_ORDER`, and verifying it
   actually boots from `nvme0n1`.

> Nothing in steps 2–6 touches the SD card, so it stays a working system throughout. If the clone
> misbehaves, re-run steps 3–6 from scratch on the NVMe; the image from step 1 is the backstop if
> the SD card itself is ever damaged.

---

### Part 2 — First boot

Insert the SD card, connect monitor + keyboard + mouse, power on.

| Platform | Default login |
|---|---|
| OrangePi | `orangepi` / `orangepi` |
| RPi 4 | `navigator` / your choice |
| RPi 5 | `navigator` / your choice (boots from the SD card at this point) |

```bash
# OrangePi only — RPi hostname was already set in Imager
sudo hostnamectl set-hostname navigator

# Full system update
sudo apt update && sudo apt full-upgrade -y
sudo reboot
```

**RPi 5 only:** stop here and do
[Enable NVMe boot](#raspberry-pi-5--enable-nvme-boot) before continuing to Part 3 — it needs
to run while still booted from the SD card.

---

### Raspberry Pi 5 — enable NVMe boot

> Do this once, after the SD card's first boot/update/reboot above. Arriving from
> [clone to NVMe later](#set-up-on-the-sd-card-now-clone-to-nvme-later)? The drive is already
> installed — start at step 2.

1. Install the NVMe drive in the M.2 HAT and confirm the Pi sees it. Installing it before
   `BOOT_ORDER` is set is fine — the EEPROM only decides what the bootloader *tries*, so the Pi
   keeps booting from the SD card until step 3 takes effect.
   ```bash
   lsblk           # nvme0n1 should be listed
   ```
   If it isn't, the PCIe port isn't enabled: the official M.2 HAT+ does it automatically via its
   HAT EEPROM, most third-party boards don't. Add `dtparam=pciex1` under `[all]` in
   `/boot/firmware/config.txt` and reboot.
2. Update the EEPROM bootloader to the latest version (older units shipped without NVMe boot
   support):
   ```bash
   sudo apt update && sudo apt install -y rpi-eeprom
   sudo rpi-eeprom-update -a
   sudo reboot
   ```
3. After reboot, set the boot order to try NVMe first and fall back to the SD card:
   ```bash
   sudo -E rpi-eeprom-config --edit
   ```
   That opens `nano`. Set this line — replacing any existing one, don't end up with two — then
   `^X`, `Y`, and **Enter** at the "File Name to Write" prompt:
   ```
   BOOT_ORDER=0xf16
   ```
   Reading right-to-left: `6`=NVMe tried first, `1`=SD card fallback, `f`=retry the sequence
   forever rather than giving up.

   **Don't verify with `sudo rpi-eeprom-config` yet — it will still show the old value, and that
   does not mean the edit failed.** The EEPROM can only be written by the bootloader at boot, so
   `--edit` builds a new bootloader image with the config baked in and *stages* it on the boot
   partition, while plain `rpi-eeprom-config` reads back the **currently running** EEPROM. Confirm
   it was staged instead:
   ```bash
   sudo rpi-eeprom-update                                       # should report an update pending
   ls -l /boot/firmware/pieeprom.upd /boot/firmware/pieeprom.sig
   ```
   If nothing was staged, skip the editor entirely — extract the config, edit the file directly,
   and apply it:
   ```bash
   sudo rpi-eeprom-config --out /tmp/bootconf.txt
   nano /tmp/bootconf.txt
   sudo rpi-eeprom-config --apply /tmp/bootconf.txt
   ```
4. Reboot, then verify both the config and where you actually booted from:
   ```bash
   sudo reboot
   ```
   ```bash
   sudo rpi-eeprom-config      # BOOT_ORDER=0xf16 should be there now
   vcgencmd bootloader_config  # reads the live EEPROM directly, independent of the tooling
   findmnt /                   # source should be /dev/nvme0n1p2, not /dev/mmcblk0p2
   df -h /                     # should show the full NVMe capacity, not the old SD size
   lsblk                       # mmcblk0 present, but nothing mounted from it
   ```
   If it still booted from the SD card, re-check `BOOT_ORDER` and that `nvme0n1p1` actually
   contains a `config.txt`.
5. If the NVMe drive isn't detected reliably (PCIe signal integrity issues are common with longer
   ribbon cables), force Gen 3 speed by adding this to `/boot/firmware/config.txt` and rebooting:
   ```
   dtparam=pciex1_gen=3
   ```

From here on, log in and do all further setup (networking, `apt full-upgrade`, Claude Code
bootstrap) on the **NVMe-booted** system — the SD card just sits in the slot as a cold
fallback and doesn't need further updates until you actually fail over to it.

---

### Part 3 — Networking (do this manually, before Claude)

> **Do this by hand — do not let Claude do it.** Claude Code needs a live internet
> connection to the model. If Claude reconfigures the Wi-Fi adapters, it drops its own
> connection mid-command and stops. Bring networking up yourself now so Claude starts from
> an already-connected machine.

Connect both Wi-Fi networks and set route metrics so internet goes out your home network,
not SoberPilot. **Lower metric wins**, so give home the lower number. (Full rationale and
the power-save / keepalive details are in [Dual Wi-Fi networking](#dual-wi-fi-networking)
below.)

```bash
# Connect to each network. nmcli usually picks the right adapter automatically, but
# SoberPilot MUST end up on wlan0 (onboard) — the USB adapter is for home/internet only.
nmcli device wifi connect SoberPilot password <password>
nmcli device wifi connect <home-ssid> password <password> ifname <usb-adapter-ifname>

# Lock SoberPilot to wlan0 so nothing can accidentally pull it onto the USB adapter later
nmcli connection modify SoberPilot connection.interface-name wlan0

# SoberPilot = high metric (600), home internet = low metric (100)
nmcli connection modify SoberPilot ipv4.route-metric 600
nmcli connection modify "<home-network-connection-name>" ipv4.route-metric 100
nmcli connection up "<home-network-connection-name>"
nmcli connection up SoberPilot
```

Find your USB adapter's interface name with `ip link show` or `nmcli device status` (it'll be
something like `wlx0013efc00bc4` — a MAC-address-derived name, not `wlan1`). To find the
connection name nmcli assigned to the home network: `nmcli connection show`.

**Verify the default route goes out your home network:**

```bash
ip route list
```

The top `default` line must be via your **home** gateway. If SoberPilot's gateway has the
lower metric, internet traffic (and Claude) tries to route through the controller's AP,
which has no internet. Fix it:

```bash
# Immediate override — drop SoberPilot's default route.
# This keeps its subnet route, so telemetry to the controller still works.
sudo ip route del default via <soberpilot-gateway>

# Confirm
ip route list          # top default line should now be via your home gateway
ping -c2 1.1.1.1       # confirm internet
```

The `nmcli ... ipv4.route-metric` commands above make the correct ordering permanent; the
`ip route del` is just an immediate override until the next reconnect. If `ip route list`
already showed home on top, you can skip the `ip route del` step.

---

### Part 4 — Bootstrap: git and Claude Code

After reboot, log back in and run:

```bash
# Node.js 20 (Claude Code runtime) + git
curl -fsSL https://deb.nodesource.com/setup_20.x | sudo -E bash -
sudo apt-get install -y nodejs git

# Claude Code
sudo npm install -g @anthropic-ai/claude-code

# Authenticate — opens a browser window for OAuth
claude login
```

#### Generate an SSH key for GitHub

```bash
ssh-keygen -t ed25519 -C "romaninim@gmail.com"
```
Accept the default path (`~/.ssh/id_ed25519`); set a passphrase or leave it blank on a
headless box like this one.

```bash
eval "$(ssh-agent -s)"
ssh-add ~/.ssh/id_ed25519
cat ~/.ssh/id_ed25519.pub
```

Copy that public key into [github.com/settings/keys](https://github.com/settings/keys) →
**New SSH key**, then verify it:

```bash
ssh -T git@github.com   # should reply "Hi <username>! You've successfully authenticated..."
```

#### Clone this repo

```bash
mkdir -p ~/dev
git clone git@github.com:romanini/AutoPilot.git ~/dev/AutoPilot
```

---

### Part 5 — Let Claude Code complete the setup

```bash
cd ~/dev/AutoPilot
claude
```

Tell Claude Code:

> "Set up this machine as the navigator computer. Follow `navigator/README.md` exactly.
> My hardware is [OrangePi Zero 2W / Raspberry Pi 4 Model B / Raspberry Pi 5]. Networking is
> already configured — do not touch the Wi-Fi adapters, connections, or routes."

Claude Code will work through the remaining System Configuration sections below — udev
rules, systemd service, OpenCPN, and the autopilot_pi plugin. **Networking is already
done in Part 3** and Claude must leave it alone, otherwise it will lose its connection to
the model.

---

## System configuration

These are the steps Claude Code follows. You can also run them manually in order.

### NetworkManager

Both platforms use NetworkManager for Wi-Fi. On RPi Ubuntu Server it is not installed
by default.

```bash
sudo apt install -y network-manager
sudo systemctl enable --now NetworkManager
```

Update netplan to delegate to NetworkManager. The existing netplan filename varies by
platform (`orangepi-default.yaml` on OrangePi, `50-cloud-init.yaml` on RPi). Replace
its contents with:

```yaml
network:
  version: 2
  renderer: NetworkManager
```

Then apply:

```bash
sudo netplan apply
```

---

### Dual Wi-Fi networking

> Done manually in [Part 3](#part-3--networking-do-this-manually-before-claude), **not** by
> Claude — reconfiguring the adapters would drop Claude's connection to the model. This
> section is the full reference for those steps.

Two Wi-Fi adapters are required:

- **`wlan0`** (onboard) → joins **SoberPilot** (the controller's AP) on `10.20.1.x`
- **USB Wi-Fi adapter** (`wlx...`) → joins your home/internet network

**Important — USB adapter is 2.4 GHz only.** The USB adapter tested with this setup
does not support 5 GHz. Any internet network you connect it to (home router, hotspot,
marina Wi-Fi) must broadcast on 2.4 GHz. On an iPhone hotspot, enable
**Settings → Personal Hotspot → Maximize Compatibility** to force 2.4 GHz.

Route metrics control which adapter handles which traffic. Lower metric wins:

```bash
# Connect to each network (nmcli will pick the right adapter automatically)
nmcli device wifi connect SoberPilot password <password>
nmcli device wifi connect <home-ssid> password <password> ifname wlx0013efc00bc4

# Lock SoberPilot to wlan0 so nothing can accidentally pull it off that interface
nmcli connection modify SoberPilot connection.interface-name wlan0

# Set metrics — SoberPilot stays on wlan0 (metric 600), internet goes out USB (metric 100)
nmcli connection modify SoberPilot ipv4.route-metric 600
nmcli connection modify "<home-network-connection-name>" ipv4.route-metric 100
```

To find the connection name nmcli assigned to the home network: `nmcli connection show`.

**Switching internet networks** (e.g. home → hotspot → marina): always specify the
USB adapter explicitly so `wlan0`/SoberPilot is never touched:

```bash
nmcli device wifi connect <new-ssid> password <password> ifname wlx0013efc00bc4
```

NetworkManager saves the password, so it will reconnect automatically next time
you're in range of that network.

---

### Keep wlan0 awake for UDP telemetry

The controller broadcasts `~APDAT` telemetry on UDP port 8888. Without these,
`wlan0` enters power-save mode and drops the broadcasts.

The config files are checked into this repo under `navigator/etc/`:

```bash
# Disable power management on wlan0 whenever the interface is added
sudo cp ~/dev/AutoPilot/navigator/etc/udev/rules.d/10-wifi-disable-powermanagement.rules \
     /etc/udev/rules.d/
sudo udevadm control --reload-rules

# Continuously ping the controller's AP gateway to keep the link alive
sudo cp ~/dev/AutoPilot/navigator/etc/systemd/system/wifi-keepalive.service \
     /etc/systemd/system/
sudo systemctl daemon-reload
sudo systemctl enable --now wifi-keepalive.service
```

To confirm telemetry is actually arriving (and watch it live), run the monitor
script checked into this repo at `navigator/usr/local/bin/apdat-monitor.py` — it
listens on UDP 8888 and redraws a single, continuously-updating snapshot of the
latest `~APDAT` packet, the same fields as the controller's telnet `p` command:

```bash
python3 ~/dev/AutoPilot/navigator/usr/local/bin/apdat-monitor.py
```

---

### Serial port permissions

OpenCPN runs sandboxed inside Flatpak and needs world-readable serial ports to open the
GPS and AIS receivers:

```bash
sudo cp ~/dev/AutoPilot/navigator/etc/udev/rules.d/70-serial-opencpn.rules \
     /etc/udev/rules.d/
sudo udevadm control --reload-rules && sudo udevadm trigger
```

---

### Desktop environment (RPi 4 and RPi 5 only)

RPi Ubuntu Server ships without a GUI. OpenCPN needs a windowed desktop, so install
XFCE (lightweight, low overhead for a nav computer):

```bash
sudo apt install -y xubuntu-desktop
sudo reboot
```

After reboot the LightDM greeter appears and you can log in graphically. The OrangePi
image ships with a desktop already — skip this step there.

#### If you get a blank screen with a blinking cursor after reboot

Stock Ubuntu's `xubuntu-desktop` doesn't ship the vc4 driver pinning that Raspberry Pi
OS includes by default, so LightDM/Xorg can crash-loop on first boot. Check:

```bash
systemctl status lightdm
cat /var/log/Xorg.0.log | tail -40
```

Two known causes, both seen back-to-back on a Pi 5:

1. **`(EE) Cannot run in framebuffer mode. Please specify busIDs for all framebuffer
   devices`** — Xorg fell back to the `fbdev` driver because it's installed and got
   probed ahead of `modesetting`. Fix:
   ```bash
   sudo apt remove -y xserver-xorg-video-fbdev
   ```

2. **`(EE) No devices detected` / `(EE) no screens found`**, with the log showing
   `modeset(G0): using drv /dev/dri/cardN` — the `modesetting` driver bound to the
   `v3d` card (GPU compute only, no display output) instead of `vc4` (the actual
   display). Confirm which card is which, then pin it explicitly:
   ```bash
   cat /sys/class/drm/card0/device/uevent   # look for DRIVER=vc4 vs DRIVER=v3d
   cat /sys/class/drm/card1/device/uevent

   sudo tee /etc/X11/xorg.conf.d/10-vc4.conf > /dev/null <<'EOF'
   Section "OutputClass"
       Identifier "vc4"
       MatchDriver "vc4"
       Driver "modesetting"
       Option "PrimaryGPU" "true"
       Option "kmsdev" "/dev/dri/cardN"
   EndSection
   EOF
   ```
   (Replace `cardN` with whichever device reported `DRIVER=vc4`.)

After either fix: `sudo systemctl restart lightdm`.

#### Auto-login

```bash
sudo tee /etc/lightdm/lightdm.conf.d/50-autologin.conf > /dev/null <<'EOF'
[Seat:*]
autologin-user=navigator
autologin-user-timeout=0
EOF
```

#### Disable screen lock and configure blank screensaver

Kill and prevent all screen locker daemons from starting. The screen still blanks after
inactivity via DPMS (power manager), but waking requires no password.

```bash
# Kill and disable all screen locker daemons
killall light-locker xfce4-screensaver 2>/dev/null
mkdir -p ~/.config/autostart
printf '[Desktop Entry]\nHidden=true\n' > ~/.config/autostart/light-locker.desktop
printf '[Desktop Entry]\nHidden=true\n' > ~/.config/autostart/xfce4-screensaver.desktop
printf '[Desktop Entry]\nHidden=true\n' > ~/.config/autostart/xscreensaver.desktop

# Clear the session lock command so nothing can trigger a lock
xfconf-query -c xfce4-session -p /general/LockCommand -s ""

# Disable xfce4-screensaver lock settings (belt and suspenders)
xfconf-query -c xfce4-screensaver -p /lock-enabled -s false -n -t bool
xfconf-query -c xfce4-screensaver -p /saver-enabled -s false -n -t bool
xfconf-query -c xfce4-screensaver -p /idle-activation/enabled -s false -n -t bool
xfconf-query -c xfce4-screensaver -p /lock/sleep-activation -s false -n -t bool

# Power manager: blank screen after 5 min, no standby/off, no lock on suspend
xfconf-query -c xfce4-power-manager -p /lock-screen-suspend-hibernate -s false -n -t bool
xfconf-query -c xfce4-power-manager -p /dpms-enabled -s true -n -t bool
xfconf-query -c xfce4-power-manager -p /blank-on-ac -s 5 -n -t int
xfconf-query -c xfce4-power-manager -p /dpms-on-ac-sleep -s 0 -n -t int
xfconf-query -c xfce4-power-manager -p /dpms-on-ac-off -s 0 -n -t int

# GNOME gsettings — xfce4-screensaver reads these as fallback
gsettings set org.gnome.desktop.screensaver lock-enabled false
gsettings set org.gnome.desktop.screensaver idle-activation-enabled false
gsettings set org.gnome.desktop.screensaver ubuntu-lock-on-suspend false
gsettings set org.gnome.desktop.lockdown disable-lock-screen true
gsettings set org.gnome.desktop.session idle-delay 0

# Prevent logind from locking or suspending
sudo mkdir -p /etc/systemd/logind.conf.d
sudo tee /etc/systemd/logind.conf.d/no-lock.conf > /dev/null <<'LOGIND'
[Login]
HandleSuspendKey=ignore
HandleLidSwitch=ignore
IdleAction=ignore
IdleActionSec=0
LOGIND
sudo systemctl restart systemd-logind

# Suppress the "Display Settings" dialog on DPMS wake
xfconf-query -c displays -p /Notify -s false -n -t bool

# Disable DPMS (RPi 4 vc4 driver doesn't forward DPMS signals to hardware)
xset s off
xset dpms 0 0 0

# Install the xrandr-based screen blanking script and autostart entry.
# The script monitors xprintidle and turns HDMI-1 off/on via xrandr.
sudo cp ~/dev/AutoPilot/navigator/usr/local/bin/screen-blank.sh /usr/local/bin/
sudo chmod +x /usr/local/bin/screen-blank.sh
cat > ~/.config/autostart/screen-blank.desktop <<'AUTOSTART'
[Desktop Entry]
Type=Application
Name=Screen Blank
Exec=/usr/local/bin/screen-blank.sh
NoDisplay=true
X-XFCE-Autostart-Phase=Applications
AUTOSTART
```

#### Desktop appearance — match OrangePi layout

Black background, no desktop icons, standard "Applications" menu (not Xubuntu Whisker
Menu):

```bash
# Black background, no wallpaper
xfconf-query -c xfce4-desktop -p /backdrop/screen0/monitor0/image-show -s false -n -t bool
xfconf-query -c xfce4-desktop -p /backdrop/screen0/monitor0/workspace0/image-style -s 0 -n -t int
xfconf-query -c xfce4-desktop -p /backdrop/screen0/monitor0/workspace0/color-style -s 0 -n -t int
xfconf-query -c xfce4-desktop -p /backdrop/screen0/monitor0/workspace0/rgba1 \
    -s 0 -s 0 -s 0 -s 1 -n -t double -t double -t double -t double
xfconf-query -c xfce4-desktop -p /backdrop/screen0/monitorHDMI-1/workspace0/image-style -s 0 -n -t int
xfconf-query -c xfce4-desktop -p /backdrop/screen0/monitorHDMI-1/workspace0/color-style -s 0 -n -t int
xfconf-query -c xfce4-desktop -p /backdrop/screen0/monitorHDMI-1/workspace0/rgba1 \
    -s 0 -s 0 -s 0 -s 1 -n -t double -t double -t double -t double

# No desktop icons
xfconf-query -c xfce4-desktop -p /desktop-icons/style -s 0
xfconf-query -c xfce4-desktop -p /desktop-icons/file-icons/show-home -s false
xfconf-query -c xfce4-desktop -p /desktop-icons/file-icons/show-trash -s false

# Standard "Applications" menu instead of Whisker Menu
xfconf-query -c xfce4-panel -p /plugins/plugin-1 -s applicationsmenu
xfce4-panel --restart
```

#### Applications menu — pin OpenCPN and Terminal Emulator to the top

The `applicationsmenu` panel plugin's `custom-menu-file` / `use-custom-menu`
xfconf properties are not honored by this XFCE build (setting them and
restarting the panel has no effect), so the pinning has to be done by editing
the merged menu file directly: `~/.config/menus/xfce-applications.menu`. This
is a user override merged (via `<MergeFile type="parent">`) on top of the
system default `/etc/xdg/xdg-xubuntu/menus/xfce-applications.menu`, so the
rest of the menu (categories, Web Browser, Mail Reader, Settings Manager,
etc.) is untouched — only the root `<Include>` and root `<Layout>` are edited.

1. Add OpenCPN to the root `<Include>` (it isn't pulled in by the
   `X-Xfce-Toplevel` category, unlike Terminal Emulator/Web Browser):

   ```xml
   <Include>
   	<Category>X-Xfce-Toplevel</Category>
   	<Filename>org.opencpn.OpenCPN.desktop</Filename>
   </Include>
   ```

2. In the root `<Layout>` (near the end of the file), move OpenCPN and
   Terminal Emulator ahead of Web Browser, and remove Terminal Emulator's old
   trailing entry so it isn't listed twice:

   ```xml
   <Layout>
   	<Filename>org.opencpn.OpenCPN.desktop</Filename>
   	<Filename>xfce4-terminal-emulator.desktop</Filename>
   	<Filename>xfce4-web-browser.desktop</Filename>
   	<Filename>xfce4-mail-reader.desktop</Filename>
   	<Separator />
   	<Filename>xfce-settings-manager.desktop</Filename>
   	...
   	<Filename>xfce4-file-manager.desktop</Filename>
   	<Filename>xfce4-run.desktop</Filename>
   </Layout>
   ```

3. Restart the panel to apply:

   ```bash
   xfce4-panel --restart
   ```

---

### OpenCPN

```bash
# Install Flatpak if not already present
sudo apt install -y flatpak
flatpak remote-add --user --if-not-exists flathub https://dl.flathub.org/repo/flathub.flatpakrepo

# Install OpenCPN
flatpak install --user flathub org.opencpn.OpenCPN

# Grant the Flatpak sandbox access to serial ports
flatpak override --user org.opencpn.OpenCPN --device=all
```

**System updates:** The GUI Software Updater silently fails on this system (no PolicyKit
auth agent). Use the terminal instead:

```bash
sudo apt update && sudo apt full-upgrade
```

#### Plugins

- **o-charts_pi** — install via OpenCPN's in-app Plugin Manager
  (Toolbox → Plugin Manager → search "o-charts"). Provides encrypted vector charts.
- **autopilot_pi** — see next section.

---

### autopilot_pi plugin

Full details and build prerequisites are in `navigator/opencpn_plugin/autopilot_pi/README.md`.

```bash
# Build prerequisites (run once)
sudo apt install -y flatpak-builder
flatpak install --user flathub org.freedesktop.Sdk//25.08

# Build and install the plugin
cd ~/dev/AutoPilot/navigator/opencpn_plugin/autopilot_pi
flatpak-builder --user --install --force-clean \
    build-dir flatpak/org.opencpn.OpenCPN.Plugin.autopilot.yaml
```

If OpenCPN refuses to load the plugin after a crash, remove the load stamp:

```bash
rm ~/.var/app/org.opencpn.OpenCPN/config/opencpn/load_stamps/libautopilot_pi
```

---

### OpenCPN autostart, maximized

OpenCPN should come up on its own after every boot/login, filling the screen, with no
manual clicking required — this is a helm display, not a desktop. OpenCPN itself
remembers whether it was last closed maximized (`FrameMax=1` in `opencpn.conf`) and
restores that, but that's fragile — anyone who closes it un-maximized breaks it on the
next boot. So autostart runs it through a small wrapper that force-maximizes the window
via `xdotool`/EWMH regardless of the saved state:

```bash
sudo apt install -y wmctrl
sudo cp ~/dev/AutoPilot/navigator/usr/local/bin/opencpn-autostart.sh /usr/local/bin/
sudo chmod +x /usr/local/bin/opencpn-autostart.sh
mkdir -p ~/.config/autostart
cp ~/dev/AutoPilot/navigator/home/navigator/.config/autostart/opencpn.desktop ~/.config/autostart/
```

`xdotool` ships by default on this image; if it's missing, `sudo apt install -y xdotool`.
The wrapper polls for the OpenCPN window for up to 30 s (Flatpak cold start can take a
few seconds), then `xdotool windowactivate`s it and hands it to `wmctrl -b
add,maximized_vert,maximized_horz`, which sets `_NET_WM_STATE_MAXIMIZED_{HORZ,VERT}` — a
real window-manager maximize (keeps decorations/panel), not a borderless fullscreen
override. Maximizing is done via `wmctrl`, not `xdotool`, because `xdotool` has no
`windowmaximize` subcommand — it never has, in any version; that's an easy one to assume
exists and only notice is missing when the script silently fails. The window search also
needs `--onlyvisible`: OpenCPN creates a couple of small hidden helper windows that also
match `--name "^OpenCPN"` case-insensitively, and without that flag the wrapper can
grab one of those instead of the real, visible main frame.

---

### Suppress the "did not shut down properly" dialog

If the Pi is powered off without OpenCPN getting a chance to exit first, OpenCPN's
own crash detection prompts on the next boot to start in normal vs. safe mode —
not appropriate for an unattended helm display. OpenCPN clears its crash marker
(`~/.var/app/org.opencpn.OpenCPN/config/opencpn/startcheck.dat`) only on a clean
exit. Confirmed on this box: closing OpenCPN's window is **not** a clean exit — it
leaves the process running headless with no window and the marker untouched;
sending it `SIGTERM` is a clean exit and removes the marker. A stub systemd
service hooks that `SIGTERM` into the shutdown sequence so it happens
automatically, however shutdown is triggered:

```bash
sudo cp ~/dev/AutoPilot/navigator/usr/local/bin/opencpn-graceful-stop.sh /usr/local/bin/
sudo chmod +x /usr/local/bin/opencpn-graceful-stop.sh
sudo cp ~/dev/AutoPilot/navigator/etc/systemd/system/opencpn-shutdown.service /etc/systemd/system/
sudo systemctl daemon-reload
sudo systemctl enable opencpn-shutdown.service
```

This only helps for an actual shutdown/reboot sequence (power button via
`logind`, `sudo shutdown`, `sudo reboot`, GUI shutdown) — it can't save you from
yanking power with no warning at all, since there's no OS shutdown sequence to
hook into in that case.

---

## Post-setup — manual GUI configuration

These steps require the graphical desktop and cannot be automated by Claude Code.

### OpenCPN — enable OpenGL (RPi 4 and RPi 5 only)

Launch OpenCPN → Toolbox → Settings → Display → tick **Enable OpenGL rendering** →
restart OpenCPN. This makes chart panning and zooming much faster.
*(Leave OpenGL off on OrangePi — the GPU driver is not reliable enough.)*

### OpenCPN — serial data connections

Toolbox → Settings → Connections → Add Connection for each device:

| Port | Baud rate | Device |
|---|---|---|
| `/dev/ttyUSB0` | 4800 | GlobalSat BU-353-N5 USB GPS (NMEA-0183) |
| `/dev/ttyACM0` | 38400 | dAISy AIS receiver (NMEA-0183) |

### OpenCPN — enable plugins

- **AutoPilot** — Toolbox → Plugin Manager → find "AutoPilot" → **Enable**.
- **o-charts_pi** — Plugin Manager → search "o-charts" → install and configure
  for encrypted vector charts.

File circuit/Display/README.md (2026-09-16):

# Display mainboard — `SM AP Display`, rev 2.2

The cockpit head-unit board. It carries a second Arduino Nano ESP32, drives the
TFT over SPI, and includes an on-board **LiPo battery + charger** so the display
can run with or without 12 V present. It also measures both the 12 V input and
the battery voltage.

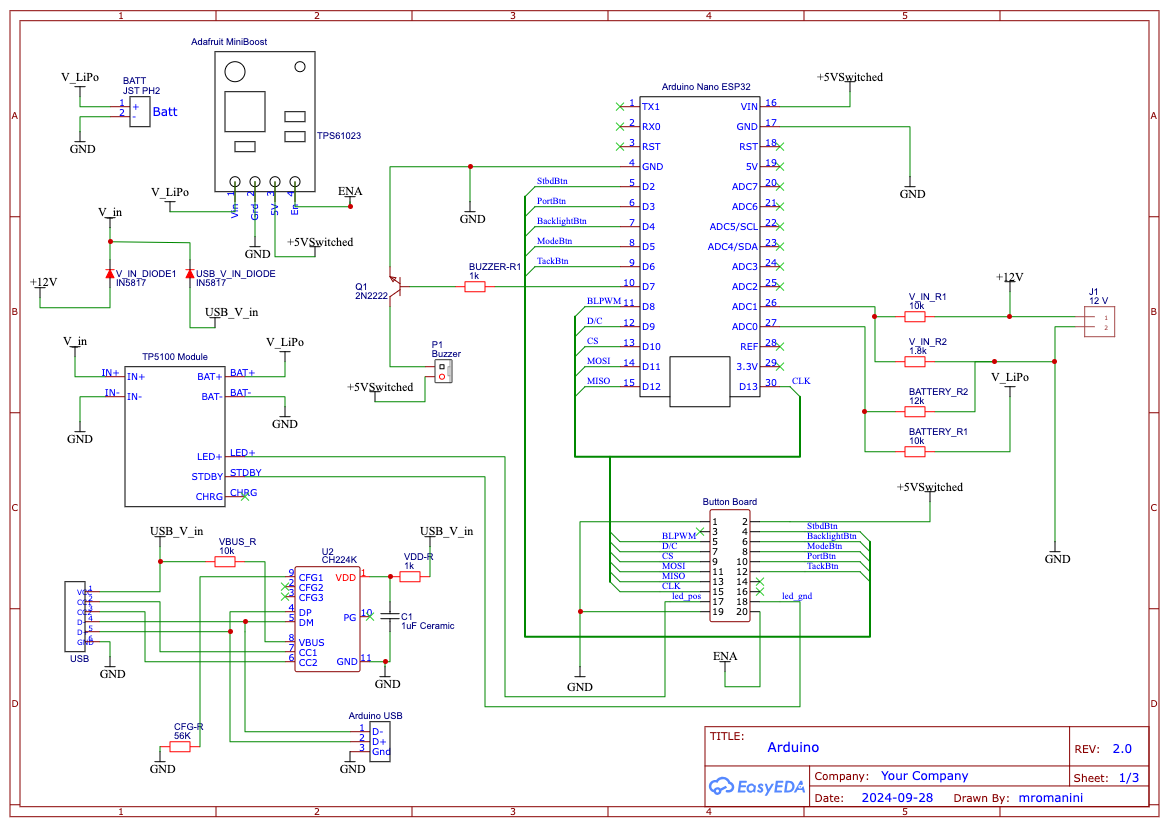
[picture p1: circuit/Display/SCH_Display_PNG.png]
Display schematic


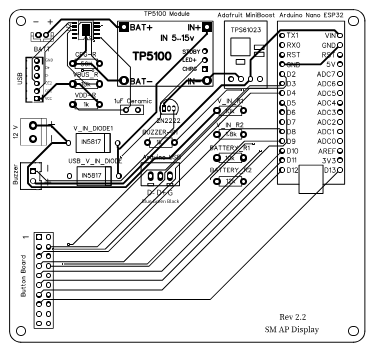
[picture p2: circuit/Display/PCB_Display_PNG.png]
Display PCB


## Components

| Ref | Part | Role |
|-----|---|---|
| **U1** | **Arduino Nano ESP32** | Runs the display firmware; SPI to the TFT (D/C, CS, MOSI, MISO, CLK) |
| **U3** | **TP5100 module** | 1–2 A Li-ion/LiPo battery charger (IN+/IN−, BAT+/BAT−, CHRG/STDBY status) |
| **TPS61023** | **Adafruit MiniBoost 5 V @ 1 A** | Boost converter — steps the LiPo up to 5 V to run the board (`+5V switched`) |
| **D1 / D2** | **1N5817** Schottky diodes | OR the 12 V input and USB 5 V onto `V_in`, the TP5100's **charger** input — neither one runs the board directly |
| **Q1** | **2N2222A** NPN transistor | Drives the buzzer from a GPIO |
| **P1** | Buzzer | Audible alert |
| **R (BUZZER-R1)** | 1 kΩ | Base resistor for Q1 |
| **V_IN_R1 / V_IN_R2** | 10 kΩ / **1.8 kΩ** | Voltage divider — measures the **12 V input** on `A1` (ratio 0.1525) |
| **BATTERY_R1 / BATTERY_R2** | 10 kΩ / **12 kΩ** | Voltage divider — measures the **LiPo battery** on `A0` (ratio 0.5455) |
| **U2** | **CH224K** | USB-C PD sink — negotiates on `CC1`/`CC2` (it provides both Rd terminations, so no external 5.1 kΩ), `CFG1` = 56 kΩ selects the requested voltage |
| — | JST-PH 2-pin (**BATT**) | LiPo battery connection |
| — | HDR-M 2×10 (**Button Board**) | Ribbon to the button / TFT pass-through board |
| — | JST-XH 1×3 / 1×5 | USB + power break-outs |

The two voltage dividers are what the firmware's `volt_meter.ino` reads to show
input and battery voltage on the LCD. It now carries this board's ratios —
0.1525 (10 kΩ/1.8 kΩ) on v-in and 0.5455 (10 kΩ/12 kΩ) on the battery, with
correction factors calibrated against a multimeter on 2026-09-13 (1.00487 on
the battery, 1.01333 on v-in — both under 1.5 %, as expected once the ratios
match the fitted resistors).

**The display always runs off its battery.** 12 V and USB are *charging* inputs
only: both feed `V_in` through their Schottky diodes, `V_in` goes to the
TP5100's `IN+` and nowhere else, and the board's own `+5V switched` rail comes
from the TPS61023 boosting the LiPo. Pulling 12 V and USB does not turn the
display off, and the boost's `EN` line (from the button board) is what actually
switches the unit on.

---

One of the [AutoPilot circuit boards](../README.md) — that README covers how the
boards fit together and the open review items. It shares a case with the
[button board](../Display-Button/README.md) and, optionally, the
[LCD carrier](../Display-LCD/README.md). Firmware:
[`../../firmware/Arduino/README.md`](../../firmware/Arduino/README.md). Enclosure: [`../../cad/display/`](../../cad/display/README.md).

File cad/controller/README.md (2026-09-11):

# Controller enclosure

The case for the **controller unit** — the box that lives below decks and runs
the autopilot. Nothing is designed yet; this directory is a placeholder that
records what the enclosure has to do.

## What goes inside

Two boards, bolted together and joined by a single 2×10 ribbon:

| Board | What it contributes to the enclosure |
|---|---|
| [`circuit/Controller/`](../../circuit/Controller/README.md) | Nano ESP32 (Wi-Fi AP), BNO085 IMU, GPS breakout, 2×4 motor header, kill-switch JST |
| [`circuit/Controller-12-volt-power/`](../../circuit/Controller-12-volt-power/README.md) | 12 V entry block, Garmin NMEA connector, USB-C, two 5×20 mm fuse holders |

See [Inside the controller unit](../../circuit/README.md#inside-the-controller-unit)
for how the two boards and the outside world connect.

## What the enclosure has to do

**Be transparent to RF.** The controller board *is* the `SoberPilot` access
point — the display, both sensors and the navigator all reach it through the
walls of this box. Plastic, not metal, and no foil-lined conduit around it. The
masthead wind sensor is the longest link in the system and has a whole mast
between it and this box.

**Hold a known, repeatable attitude.** The BNO085 inside is the boat's compass,
so the enclosure's orientation *is* the heading reference. It wants to sit level
and square to the centreline, on a mount that cannot creep or be refitted a few
degrees off. It does not have to be perfect — `controller/compass.ino` carries a
`COMPASS_MOUNT_OFFSET_DEG` trim (18° as of the last bench calibration) — but
whatever offset is dialled in has to stay true, so the box should only bolt down
one way.

**Keep iron and magnets away from the IMU.** Stainless or nylon fasteners, and
give the mounting location a wide berth from speakers, DC cabling runs and
anything with a motor in it.

**Take five cable entries**, all on the power board's side except the motor
lead: 12 V supply, the 7-conductor Garmin NMEA-0183 loom, USB-C, the 2×4 motor
cable out to the driver, and the 2-pin kill switch. Glands or a gasketed entry
plate — this is a dry location but a bilge is never guaranteed dry.

**Leave the fuses reachable.** The Acc and Garmin 5×20 mm holders are the only
serviceable parts in the unit; blowing one should not mean unbolting the box.

**Leave a USB port reachable**, or accept opening the case to reflash. Both
boards break out USB.

An open question worth settling before the box is drawn: the **GPS is on the
controller board**, so wherever this unit mounts needs sky view, or the design
needs to grow a connector for an external antenna.

## Status

Placeholder only — no FreeCAD documents yet. The
[wind sensor](../wind/README.md) is the one enclosure that is finished, and its
directory is the pattern to follow: FreeCAD sources and a build write-up.

```
cad/controller/
├── README.md     this file
└── *.FCStd       FreeCAD sources — none yet
```

STLs are not kept in the repo; export them from the `.FCStd` documents when you
are ready to print.

---

One of the [AutoPilot enclosures](../README.md) — that README covers the layout
convention and the constraints every case shares.

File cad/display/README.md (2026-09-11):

# Display enclosure

The case for the **cockpit head unit** — the screen and buttons the helm
actually touches. Nothing is designed yet; this directory is a placeholder that
records what the enclosure has to do.

## What goes inside

A stack of two or three boards plus a panel and a battery:

| Board | What it contributes to the enclosure |
|---|---|
| [`circuit/Display/`](../../circuit/Display/README.md) | Nano ESP32, TP5100 charger, TPS61023 boost, buzzer, JST-PH to the LiPo |
| [`circuit/Display-Button/`](../../circuit/Display-Button/README.md) | Five tactile buttons and the illuminated power switch — both need panel cutouts |
| [`circuit/Display-LCD/`](../../circuit/Display-LCD/README.md) | Optional ST7365P carrier with its 40-pin FPC tail |
| — | A 3.5" 320×480 panel: either an HX8357 module or the VIEWE ST7365P |
| — | A LiPo cell — the only rail that actually runs the unit |

They chain mainboard → 2×10 ribbon → button board → 8-pin JST-XH → panel, so
the **stack height and the ribbon service loops set the case depth**. See
[Inside the display unit](../../circuit/README.md#inside-the-display-unit).

## What the enclosure has to do

**Survive the cockpit.** Rain, spray, sun and the occasional boot. Gasketed lid,
UV-stable material, and a light colour — this is the one box that sits in direct
sun all day.

**Frame the screen.** A window over the 3.5" 320×480 active area, with a bezel
that hides the panel border without eating pixels. The two supported panels do
not share an outline: the HX8357 module bolts up as a board, while the ST7365P
is a bare panel on a flex tail into the carrier, which needs clearance for the
FPC and its bend radius. Either the case supports both, or it commits to one and
says so.

**Carry six controls.** Five button plungers or a membrane over the tactile
switches — **Port, Enable, Mode, Starboard, Tack** — plus a cutout for the
illuminated 4-pin power switch. The buttons are the part most likely to leak and
the part most often used with wet gloves, so plunger seals and travel are worth
prototyping before the rest of the case is finalised.

**Hold the battery, and let it be replaced.** The display always runs off its
LiPo — 12 V and USB only charge it — so a dead cell means a dead unit. It needs
a retained pocket, strain relief on the JST-PH lead, and a back that opens
without disturbing the panel seal.

**Be transparent to RF.** The display is a station on `SoberPilot`; no metal
bezel wrapping the ESP32's antenna.

**Decide what stays reachable.** The 12 V charge lead has to enter somehow, and
USB-C is how the unit gets reflashed — either a sealed port with a cap, or
accept opening the case.

## Status

Placeholder only — no FreeCAD documents yet. The
[wind sensor](../wind/README.md) is the one enclosure that is finished, and its
directory is the pattern to follow: FreeCAD sources and a build write-up.

```
cad/display/
├── README.md     this file
└── *.FCStd       FreeCAD sources — none yet
```

STLs are not kept in the repo; export them from the `.FCStd` documents when you
are ready to print.

---

One of the [AutoPilot enclosures](../README.md) — that README covers the layout
convention and the constraints every case shares.

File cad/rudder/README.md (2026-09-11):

# Rudder sensor enclosure

The case and bracket for the **rudder angle sensor** — the unit down by the
quadrant that tells the controller where the rudder actually is. The boat is
wheel-steered, so without this the controller is steering blind. Nothing is
designed yet; this directory is a placeholder that records what the enclosure
has to do.

## What goes inside

One board, and one magnet that is not on it:

| Part | What it contributes to the enclosure |
|---|---|
| [`circuit/Sensor-Rudder/`](../../circuit/Sensor-Rudder/README.md) | Nano ESP32 + AS5600L encoder, 2-pin 3.5 mm terminal block for 12 V |
| — | A **diametrically magnetised** magnet, mounted on the rudder stock itself |

## What the enclosure has to do

This is really two problems: a sealed box for the board, and a bracket that
holds the AS5600L in a fixed relationship to a rotating magnet.

**Put the magnet on the axis.** The AS5600L reads the *direction* of the field
across its face, so the magnet has to sit on the rudder stock's axis of rotation
and turn with it, with the chip stationary and centred over it. Off-axis is the
one error the firmware cannot calibrate away.

**Hold a small, constant air gap.** A couple of millimetres, held rigid — a
bracket that flexes as the quadrant loads up turns rudder force into rudder
angle. The board reports the AS5600L's own magnet-detect flag in every
`~APRUD,<angle>,<magnet_ok>$` packet, so the gap can be checked live from a
laptop on `SoberPilot` rather than by eye.

**Stay rigid rather than precise.** Centring is a runtime command
(`~APCMD,z$` with the rudder amidships, persisted in NVS), so the bracket does
not have to be angularly accurate — it just must not move afterwards. Nothing
ferrous near the magnet.

**Survive a wet locker.** A lazarette or quadrant space is the wettest place any
of these units lives short of the masthead. Sealed box, gasketed lid, gland for
the single 12 V pair — which is the whole point of putting this unit on Wi-Fi
rather than running a signal cable forward.

**Be transparent to RF.** This is a station on `SoberPilot`, usually as far from
the controller as anything below decks gets, often with a bulkhead or two in
between. Plastic case, and worth checking link quality at the chosen mounting
spot before committing to it.

## Status

Placeholder only — no FreeCAD documents yet. The
[wind sensor](../wind/README.md) is the one enclosure that is finished, and its
directory is the pattern to follow: FreeCAD sources and a build write-up.

```
cad/rudder/
├── README.md     this file
└── *.FCStd       FreeCAD sources — none yet
```

STLs are not kept in the repo; export them from the `.FCStd` documents when you
are ready to print.

---

One of the [AutoPilot enclosures](../README.md) — that README covers the layout
convention and the constraints every case shares.

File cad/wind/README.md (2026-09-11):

# Wind sensor

Masthead **wind speed and direction** sensor for the AutoPilot project.

A cup anemometer and a wind vane on a common 3D-printed housing, both read
magnetically — no slip rings, no exposed contacts. Four alternating magnets on
the cup-wheel shaft sweep past a hall sensor for speed; a diametric magnet on the
vane shaft is read by an **AS5600** magnetic encoder for direction (0.1°,
contactless). An **Arduino Nano ESP32** on the board joins the controller's
`SoberPilot` Wi-Fi and reports over UDP, so the only thing that runs down the
mast is 12 V — usually already there for the anchor light.

Derived from the **Yachta** wind sensor by Norbert Walter
([Open Boat Projects](https://open-boat-projects.org/en/zusammenbauanleitung-windsensor-yachta/)),
rebuilt around the Nano ESP32 to match the rest of this project.

**→ [Assembly.md](Assembly.md) — full build instructions.**

---

## Where it fits in AutoPilot

| | |
|---|---|
| Joins | `SoberPilot` Wi-Fi as a station, like a display or the rudder sensor |
| Sends | wind speed + angle to the controller |
| Ends up in | `~APDAT` telemetry → TFT head unit, and `autopilot_pi` in OpenCPN |
| Enables later | a wind-vane steering mode — hold an apparent wind angle instead of a compass heading |

Background and the options that were weighed:
[`.claude/docs/FutureUpgrades-WindAndRudder.md`](../../.claude/docs/FutureUpgrades-WindAndRudder.md).

## What is in this directory

```
cad/wind/
├── README.md                       this file
├── Assembly.md                     build instructions
└── *.FCStd                         FreeCAD documents — the editable source
```

The board lives in [`circuit/Sensor-Wind/`](../../circuit/Sensor-Wind/README.md);
build photos in [`assets/wind/`](../../assets/wind/).

### Printed parts

**No STLs are kept in the repo.** Open the `.FCStd` and export a mesh when you
are about to print — see [Exporting a printable mesh](#exporting-a-printable-mesh)
below. The German names are the upstream IGES masters each FreeCAD document was
built from; they are no longer in the repo either, but they explain the naming
and match the upstream Yachta project if you go looking there.

| FreeCAD document ← upstream name | Qty | What it is |
|---|---|---|
| `BottomHousing.FCStd` ← `Unterteil` | 1 | **Modified.** Main housing: board pocket, bearing seat, arm socket |
| `TopCover.FCStd` ← `Oberteil` | 1 | **Modified.** Cover; its hub carries the vane bearing |
| `TopCap.FCStd` ← `Oberteil` | 1 | Top cap |
| `BottomBearingHolder.FCStd` ← `Unterteil-2` | 1 | **Modified.** Carries the two lower bearings; stem 5 mm longer |
| `MagnetHolder.FCStd` ← `Magnethalter` | 1 | Holds the four speed magnets |
| `CupWheelHub.FCStd` ← `Loeffel_mitte` | 1 | Hub the three cups glue into |
| `CupRound.FCStd` ← `Loeffel_rund` | **3** | The cups |
| `CupPointed.FCStd` ← `Loeffel_spitz` | — | Alternative cup profile |
| `WindVane.FCStd` ← `Windfahne` | 1 | The vane blade |
| `MastBase.FCStd` ← `Fuss_regler` | 1 | Mast base the standpipe plugs into |

`WindexBase.FCStd` is an upstream alternative top, not used in this build.

> **Two parts of the build have no FreeCAD source.** The vane supports —
> `fane_support_big` (the 78 mm dome the vane mounts on, ×1) and
> `fane_support_smal` (clamps the vane bearing into the cover hub, ×1) — only
> ever existed as upstream meshes, and so did the unused `magnet_holder_2` and
> `cup_pointed_long` variants. They are not regenerable from anything in this
> directory. Pull them out of git history when you print:
>
> ```
> git show 3b8b956:cad/wind/3D-Parts/fane_support_big.stl > fane_support_big.stl
> git show 3b8b956:cad/wind/3D-Parts/fane_support_smal.stl > fane_support_smal.stl
> ```
>
> Or fetch them from
> [upstream](https://github.com/norbert-walter/Windsensor_Yachta). Modelling
> them properly is the obvious loose end here.

### What was changed from upstream

The Nano ESP32 board is **103.25 × 40.13 mm** — longer than the 70 mm housing —
so `BottomHousing` and `TopCover` grew a nose to cover it:

- Board pocket now follows the board outline with 0.4 mm clearance
- A **49 × 23 × 14.8 mm well** under the nose for the Nano, which hangs 14 mm
  below the board in its socket
- The **arm-tube socket moved 47.8 mm outboard along its own axis** to clear the
  Nano. Same 20° angle, same Ø10 bore — so the same tube and mast base still fit,
  **the tube just needs shortening by 47.8 mm**
- A fifth cover screw at the nose tip
- Cable duct and riser bring the 12 V cable to the terminal block

Everything within **r = 20 mm of the axis is untouched** — bearing seats, magnet
gaps, mounting bosses and screw positions are all exactly as the original, so
the rotating assembly is unaffected.

**`BottomBearingHolder` — stem lengthened 36 → 41 mm.** The relocated arm
socket reaches about 2.5 mm deeper than the bare tube did, into the band the cup
wheel sweeps. Rather than thin the socket wall, the bearing carrier's stem was
stretched 5 mm, which drops the cup wheel clear with margin.

This works because the rotating assembly hangs from the **top** (625) bearing at
the flange end, and the speed-magnet holder sits up there under the hall sensor.
Stretching the stem moves only the lower (695) bearing and the cup wheel that
clamps against it — **the 1 mm magnet gap is untouched**, and so are the Ø31
spigot, the Ø35 flange, both bearing seats and the three Ø3.2 screw holes. The
inserted 5 mm is a prism of the carrier's own cross-section, so the taper simply
pauses rather than stepping.

Two consequences:

- **The shaft screw must change** — see the shopping list. Both bearings run on
  the *smooth* part of the shank, and the bearing span goes 30 → 35 mm, which
  the original M5×60's 35 mm plain shank no longer covers with any margin.
- **The cups now hang 5 mm lower.** Check clearance to anything under the
  masthead — anchor light, mast crane, backstay.

### Editing the CAD

The `.FCStd` documents in this directory are the editable source, and the only
one. The three modified parts were originally generated from the upstream German
IGES masters by a build script, which also cut the board pocket using the outline
read straight out of the EasyEDA export. **Neither the IGES masters nor that
script are in the repo any more** — the FreeCAD documents are what is kept. Both
are still in the git history if the generated route is ever wanted back.

Editing happens in the FreeCAD GUI, which the documents are built for: the
modified parts keep a live Part-workbench boolean tree (`OriginalHousing` +
`SnoutBody` + `SocketKeel`, with the pockets cut out of it), so every feature is
still parametric rather than a frozen mesh.

#### Exporting a printable mesh

Meshes are generated on demand and **never committed** — a checked-in STL only
becomes a stale copy of a model that has moved on. Either export from the GUI
(select the part → *File → Export…* → STL), or from the command line:

```
freecadcmd -c "
import Mesh, FreeCAD
d = FreeCAD.open('BottomHousing.FCStd')
Mesh.export([d.Objects[-1]], '/tmp/BottomHousing.stl')
"
```

Write the result somewhere outside the repo, or clean it up before committing.

Two things the script used to handle, which are now manual:

- **If the PCB outline changes**, the board pocket no longer follows it
  automatically — re-cut it against the new
  [`circuit/Sensor-Wind/`](../../circuit/Sensor-Wind/README.md) export.
- **The bearing carrier's extra 5 mm** was a `STEM_EXTRA` constant; it is now
  baked into `BottomBearingHolder.FCStd`. Change it in the model if the cups
  need to drop further.

---

## Shopping list

### Bearings, fasteners, magnets

All stainless — **A4 (V2A/316)**, not A2. This lives at the masthead.

| Qty | Item | Notes | Buy |
|---|---|---|---|
| 2 | Ball bearing **625** (16×5×5 mm) | Stainless. ABEC9 if you can get it | [Amazon](https://www.amazon.com/%EF%BC%BB12-Pack%EF%BC%BD625-2RS-Ball-Bearings-Miniature/dp/B0BRQP2QG7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) |
| 1 | Ball bearing **695** (13×5×4 mm) | Stainless; full-ceramic is a nice upgrade here | [Amazon](https://www.amazon.com/uxcell-695-2RS-Miniature-Bearings-5x13x4mm/dp/B0CRVKG96C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) |
| 4 | Neodymium bar magnet **5 × 1.5 × 1 mm** | Speed ring — **fit alternating**, see note | [buyneomagnets](https://www.buyneomagnets.com/p/5x1-5x1-mm-thick-neodymium-block-magnets-n35-powerful-small-rectangular-magnets-tiny-magnetic-blocks-lowes-home-depot/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) · [UMagnets](https://www.umagnets.com/p/neodymium-block-magnet-5-x-1-5-x-1mm-thick-strong-n35-strong-square-rare-earth-rectangular-magnets-100-pack/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) |
| 1 | Neodymium magnet **10 × 5 mm N45 disc** | Direction — **must be diametric**, see note | [buyneomagnets](https://www.buyneomagnets.com/p/10mm-x-5mm-diametrically-magnetized-disc-magnet-neodymium-round-magnets-n35-rare-earth-radial-magnets-20-pack/) · [umagnets](https://www.umagnets.com/p/n42-10mm-x-5mm-strong-disc-neodymium-magnets-round-rare-earth-magnets-ebay/) |
| 1 | **M5×70 screw, DIN 931** (partially threaded) | **Changed from M5×60.** Cup-wheel shaft. Needs ≥40 mm of *plain* shank — both bearings run on it, span is now 35 mm. DIN 931 M5×70 gives 48 mm plain | [McMaster](https://www.mcmaster.com/92095A484/) |
| 1 | **M5×25** countersunk screw | Vane shaft | [McMaster](https://www.mcmaster.com/92010A330/) |
| 1 | **M6×60** Allen screw | Vane counterweight — mass matters more than grade | [McMaster](https://www.mcmaster.com/91263A468/) |
| 11 | **M3×10** Allen screws | Housing. 3×10 wood screws also work | [Amazon](https://www.amazon.com/Etauwe-100-Piece-10mm-Self-Tapping-Screws/dp/B0G7ZPTS7B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) |
| 3 | **M5** washers | | [McMaster](https://www.mcmaster.com/93475A240/) |
| 1 | **M5** nut | | [McMaster](https://www.mcmaster.com/91828A241/) |
| 2 | **M5** stop nuts (nyloc) | | [McMaster](https://www.mcmaster.com/94645A102/) |
| 1 | **Ø10 × 1 mm wall × 300 mm** aluminium tube | Standpipe — **cut 47.8 mm shorter than upstream** | [Amazon - Alunium](https://www.amazon.com/VictorsHome-Aluminum-Thickness-Seamless-Straight/dp/B09VDKB1NG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) · [Amamzon - Stainless](https://www.amazon.com/MECCANIXITY-Stainless-Capillary-Thickness-Construction/dp/B0G52G6S5T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) |

> **The M5×70 is the one item worth reading twice.** It replaces the M5×60 in the
> upstream list because the carrier stem is 5 mm longer. Both bearings have a
> 5 mm bore and must ride on the **unthreaded** part of the shank — a bearing
> sitting on thread run-out will be sloppy and will chew the bore. Fully
> threaded M5×70 is the wrong part. You want DIN 931 (partially threaded, 22 mm
> of thread, 48 mm plain). Head must be a cross-recess or hex that still drops
> into the magnet-holder recess.

> **The two magnets are the parts most often bought wrong.**
>
> **Direction magnet — must be *diametrically* magnetised** (poles across the
> diameter, not top to bottom). An axial magnet of identical size will not work
> with an AS5600. Sources disagree on size: the build photo is annotated
> **10 × 5 mm N45 disc**.
>
> **Speed magnets — four small bars, fitted alternating N-S-N-S.** All four 5 × 1.5 × 1 mm the
> same way round makes every wind speed read exactly **double**. 

### Consumables

| Item | Notes | Buy |
|---|---|---|
| PETG or ASA filament, **white or light** | Dark filament softens in masthead sun; black PETG is unsuitable | [Amazon](https://www.amazon.com/s?k=white+PETG+filament+1.75mm) |
| Clear lacquer that bonds to PETG without primer | Upstream specifies Dupli-Color Aerosol Art — 3 thin coats | [Amazon](https://www.amazon.com/s?k=clear+coat+spray+lacquer+UV+resistant+plastic) |
| 2-component acrylic adhesive, retains some elasticity | Upstream specifies **Weicon RK-1300**. Rigid glues crack over the −10 … +90 °C swing | [Amazon](https://www.amazon.com/s?k=Weicon+RK-1300+structural+acrylic+adhesive) |
| Superglue | Captive nuts and the small magnets only | [Amazon](https://www.amazon.com/s?k=cyanoacrylate+super+glue+gel) |
| Threadlocker (blue) | Cup-wheel shaft, after setting the running clearance | [Amazon](https://www.amazon.com/s?k=loctite+242+243+blue+threadlocker) |
| 99 % isopropyl or ethanol + cotton buds | Degrease before lacquering | [Amazon](https://www.amazon.com/s?k=99%25+isopropyl+alcohol) |
| Silicone or fine machine oil | Bearings | [Amazon](https://www.amazon.com/s?k=fine+machine+oil+precision+bearing) |
| 2-core cable, masthead to 12 V | ~50 mA, so conductor size is not critical; UV-resistant jacket is | [Amazon](https://www.amazon.com/s?k=marine+2+conductor+tinned+wire+18awg) |

### Electronics you will need to buy

**You are fabricating your own board**, so this is the component list, not a
finished module. Board files, schematic and Gerbers are in
[`circuit/Sensor-Wind/`](../../circuit/Sensor-Wind/README.md).

| Ref | Part | Role | Buy |
|---|---|---|---|
| U1 | **Arduino Nano ESP32** | Wi-Fi + firmware. Socketed on the **underside** | [Amazon](https://www.amazon.com/s?k=Arduino+Nano+ESP32) |
| DIRECTION | **AS5600L-ASOT** (SOIC-8) | Magnetic angle encoder — wind direction | [Amazon](https://www.amazon.com/s?k=AS5600+magnetic+encoder) · [LCSC C499458](https://www.lcsc.com/search?q=AS5600L-ASOT) |
| SPEED | **SS40AF** hall sensor (TO-92) | Wind speed pulses. A3144 is a common substitute | [Amazon](https://www.amazon.com/s?k=A3144+hall+effect+sensor+TO-92) |
| TEMP | **DS18B20** (TO-92) | Air temperature (optional) | [Amazon](https://www.amazon.com/s?k=DS18B20+TO-92+temperature+sensor) |
| R1, R2, R4 | 4.7 kΩ resistor | I²C pull-ups and 1-Wire pull-up | [Amazon](https://www.amazon.com/s?k=resistor+assortment+kit+1%25) |
| R3 | 10 kΩ resistor | Hall sensor pull-up | (same kit) |
| C1 | 100 nF ceramic capacitor | Decoupling | [Amazon](https://www.amazon.com/s?k=100nF+ceramic+capacitor+kit) |
| J2 | 2-way 3.5 mm screw terminal | 12 V in | [Amazon](https://www.amazon.com/s?k=3.5mm+pitch+2+pin+screw+terminal+block+pcb) |

Also a **15-pin socket header pair** (2 × 15, 2.54 mm) for the Nano — it mounts
in a socket so it can be pulled without unsoldering, which is why the housing
has a 14 mm well beneath it —
[Amazon](https://www.amazon.com/s?k=15+pin+female+header+2.54mm).
And the board itself: [PCBWay](https://www.pcbway.com/) or
[JLCPCB](https://jlcpcb.com/) will take the Gerbers in
[`circuit/Sensor-Wind/`](../../circuit/Sensor-Wind/README.md) directly.

> The upstream project sells a populated ESP8266 board through Aisler. That board
> is **not** compatible with this housing — the pocket, the well and the
> connector positions are all cut for the Nano ESP32 board in `circuit/Sensor-Wind/`.

---

## Credits

Original design by **Norbert Walter**, [Open Boat Projects](https://open-boat-projects.org/).
Hardware and documentation **CC-BY-NC-SA**; firmware **GPL-3.0**.
Upstream: <https://github.com/norbert-walter/Windsensor_Yachta>

---

One of the [AutoPilot enclosures](../README.md) — that README covers the layout
convention and the constraints every case shares.

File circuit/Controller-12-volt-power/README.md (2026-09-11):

# 12-volt power board — `SM AP Power`, rev 1.0

A passive **power-distribution and interconnect board** that lives next to the
controller. It brings the boat's 12 V supply, the Garmin NMEA feed and a USB port
onto one board, fuses them, and hands them off to the controller through a single
ribbon header.

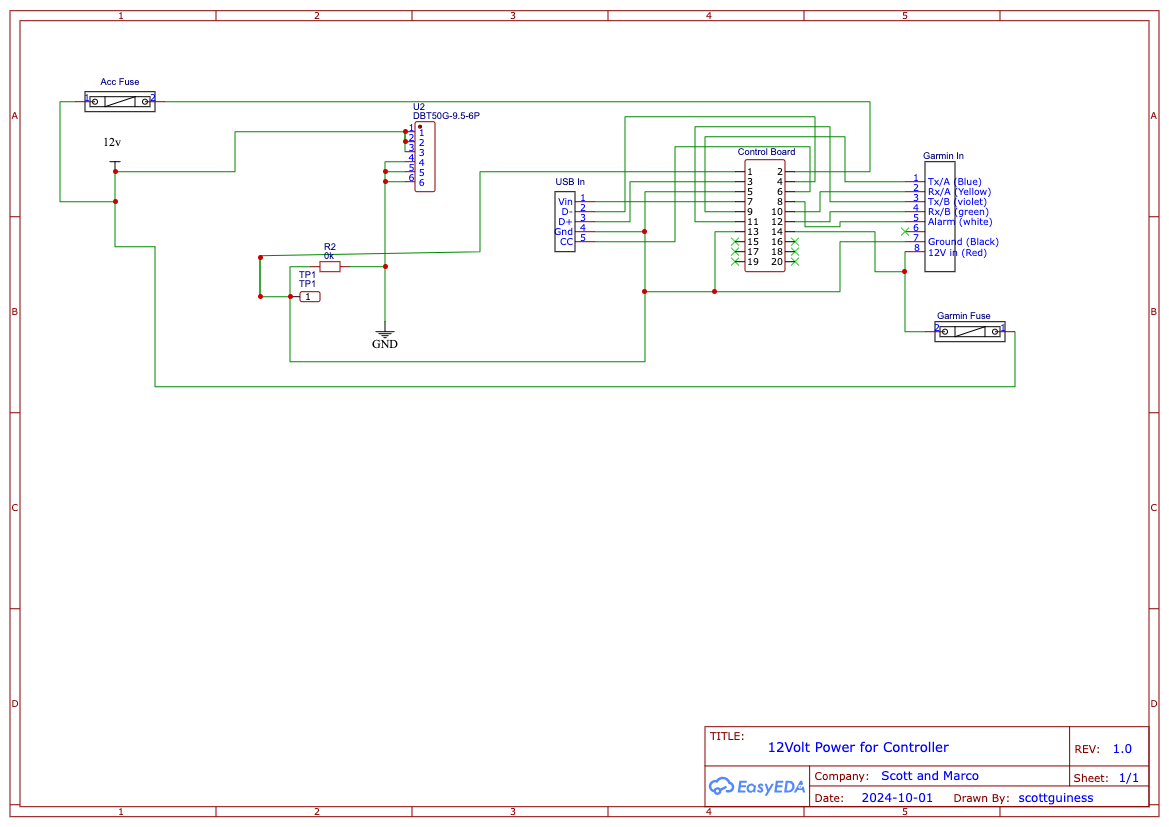
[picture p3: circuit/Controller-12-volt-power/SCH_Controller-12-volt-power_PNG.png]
12 V power schematic


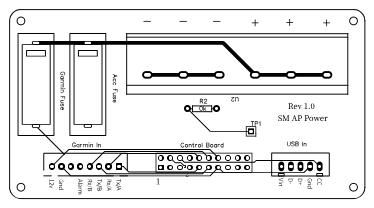
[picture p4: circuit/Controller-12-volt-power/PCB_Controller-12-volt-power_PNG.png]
12 V power PCB


## Components

| Ref | Part | Role |
|-----|---|---|
| **U2** | **DBT50G-9.5-6P** terminal/power connector | Main 12 V power entry block |
| — | **Garmin In** connector | Garmin NMEA-0183 feed — Tx/A (blue), Rx/A (yellow), Tx/B (violet), Rx/B (green), Alarm (white), Ground (black), 12 V (red) |
| — | **USB-C** connector | USB-In break-out (Vin / D− / D+ / GND / CC) |
| — | 5×20 mm fuse holder (BLX-A) | **Acc Fuse** — protects the 12 V accessory rail |
| — | 5×20 mm fuse holder (BLX-A) | **Garmin Fuse** — protects the Garmin 12 V feed |
| **R2** | **0 Ω** link (with test point **TP1**) | The *only* bridge between the ribbon/Garmin/USB ground and the main power-connector ground — a star-ground link that can be lifted to break a loop or measure return current. Marked `0k` on the schematic |
| — | HDR-M 2×10 | **Control Board** header — ribbon to the controller's Power Distribution header |

Everything here is wiring and protection: it consolidates power and the Garmin
NMEA wiring, fuses the 12 V rails, and routes them to the controller over the
2×10 ribbon so the controller board itself stays clean.

---

One of the [AutoPilot circuit boards](../README.md) — that README covers how the
boards fit together and the open review items. It shares a case with the
[controller board](../Controller/README.md). Firmware:
[`../../firmware/Arduino/README.md`](../../firmware/Arduino/README.md). Enclosure: [`../../cad/controller/`](../../cad/controller/README.md).

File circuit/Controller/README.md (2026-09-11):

# Controller board — `SM AP Controller`, rev 2.1

The main board of the autopilot. It carries the Arduino Nano ESP32 and all of
its sensors, and breaks out the steering-motor and power connections.

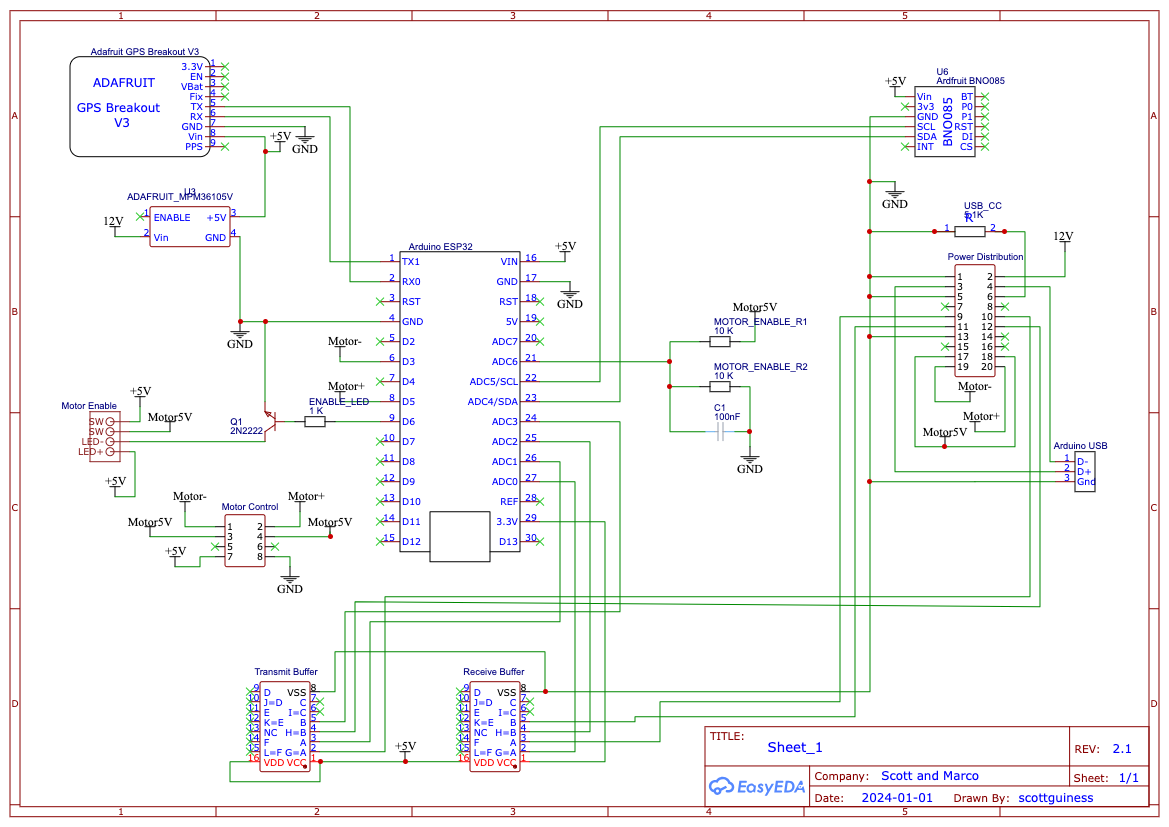
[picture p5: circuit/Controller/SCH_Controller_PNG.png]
Controller schematic


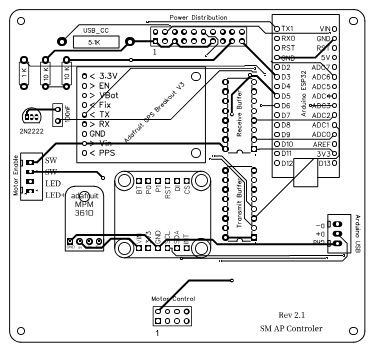
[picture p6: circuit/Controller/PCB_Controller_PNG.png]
Controller PCB


## Components

| Ref | Part | Role |
|-----|---|---|
| **U1** | **Arduino Nano ESP32** | The brain — runs the controller firmware, the PID steering loop, and the `SoberPilot` Wi-Fi access point |
| **U6** | **Adafruit BNO085** (BNO08x 9-DOF IMU) | Fused compass / heading, pitch and roll, plus motion "stability" — connected over I²C (SCL/SDA) |
| **U4 / V3** | **Adafruit GPS Breakout** | GPS position, speed and course, NMEA over the ESP32 UART (TX/RX) |
| **U3** | **Adafruit MPM3610 5 V module** | 12 V → 5 V buck regulator that powers the board. Its `ENABLE` pin is an explicit no-connect — it relies on the pull-up to `VIN` on Adafruit's breakout |
| **U2** | **CD4010BE** hex buffer (TI) | "Receive Buffer" — level-shifts/buffers the incoming serial line |
| **U5** | **CD4010BE** hex buffer (TI) | "Transmit Buffer" — level-shifts/buffers the outgoing serial line |
| **R1** | 47 Ω | Current limit for the on-board **Debug LED** |
| **R2** | 5.1 kΩ | USB-C `CC` pull-down on the Arduino USB connector |
| — | HDR-M 2×4 | **Motor Control** header (out to the steering-motor driver) |
| — | JST-XH 2-pin | **Kill Switch** input |
| — | HDR-M 2×10 | **Power Distribution** header (12 V in / interconnect to the 12-volt-power board) |
| — | JST-XH 1×3/1×4 | Sensor + USB break-out connectors |

The two **CD4010 hex buffers** sit between the ESP32's 3.3 V logic and the
external 5 V / NMEA serial world, buffering the receive and transmit lines so the
Garmin / GPS serial signals are cleanly level-matched before they reach the
microcontroller.

---

One of the [AutoPilot circuit boards](../README.md) — that README covers how the
boards fit together and the open review items. It shares a case with the
[12-volt power board](../Controller-12-volt-power/README.md). Firmware:
[`../../firmware/Arduino/README.md`](../../firmware/Arduino/README.md). Enclosure: [`../../cad/controller/`](../../cad/controller/README.md).

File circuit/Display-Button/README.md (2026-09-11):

# Button / LED board — `SM Button board V2`, rev 1.0

The board behind the cockpit buttons. It hosts the five physical buttons, the
illuminated power switch connector, and **passes the TFT's SPI bus through** to
the display panel.

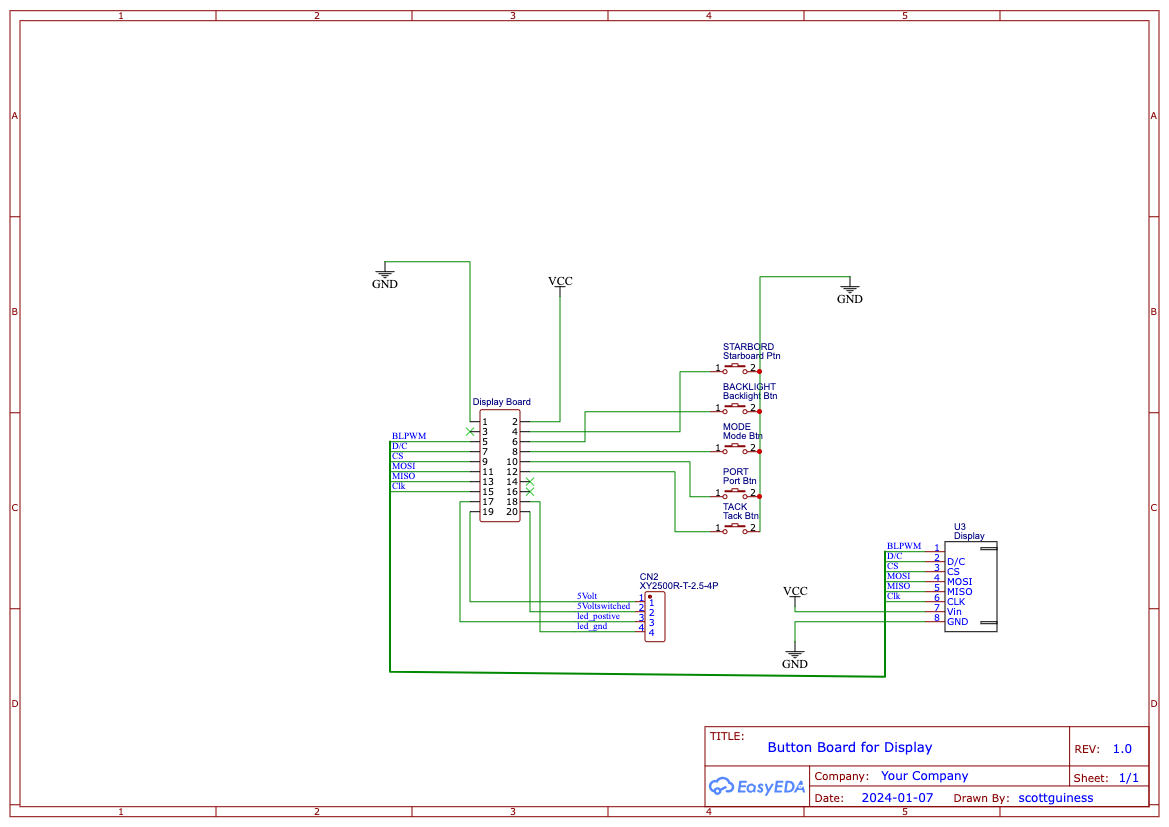
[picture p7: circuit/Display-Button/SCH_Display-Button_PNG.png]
Button board schematic


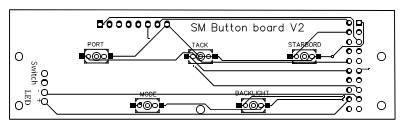
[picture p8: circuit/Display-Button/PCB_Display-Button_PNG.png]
Button board PCB


## Components

| Ref | Part | Role |
|-----|---|---|
| 5 × | **K2-1107ST** SMD tactile switches | The cockpit buttons: **Port**, **Enable** (compass), **Mode** (GPS), **Starboard**, **Tack** |
| **U3** | JST-XH 8-pin | Connector to the TFT — passes D/C, CS, MOSI, MISO, CLK, Vin, GND |
| **CN2** | **XY2500R-T-2.5-4P** | **Illuminated power switch.** Pins 1/2 (net-named `5Volt` / `5Voltswitched`, but actually GND and the TPS61023's `EN` on the mainboard) are the switch contacts; pins 3/4 are its LED, driven by the TP5100's `LED+` / `STDBY` charge-status pins |
| — | HDR-M 2×10 (**Display Board**) | Ribbon back to the display mainboard |

Functionally this board sits between the display mainboard and the panel: the
2×10 ribbon brings the button signals and SPI bus over from the mainboard, the
buttons tie into the matching net labels, and the SPI bus continues out of U3 —
either straight to an HX8357 module, or to the
[LCD carrier board](../Display-LCD/README.md). CN2 powers the button backlights.

The display mainboard calls the fifth button's net `BacklightBtn`, and that has
now come true on the firmware side: enable/disable has moved to the motor
**kill switch** on the controller (`firmware/Arduino/controller/motorenable.ino`),
which is the only thing that engages navigation. The firmware reads that pin
(`D4`) as `AUX_BUTTON_PIN`; it still carries auto-tune start/abort and is
otherwise free for the backlight the net name promises.

---

One of the [AutoPilot circuit boards](../README.md) — that README covers how the
boards fit together and the open review items. It shares a case with the
[display mainboard](../Display/README.md). Firmware:
[`../../firmware/Arduino/README.md`](../../firmware/Arduino/README.md). Enclosure: [`../../cad/display/`](../../cad/display/README.md).

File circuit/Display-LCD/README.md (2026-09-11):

# LCD carrier — `AutoPilot LCD Carrier`, v1.0

Adapts the **VIEWE UEED035HV-RX40-L001A** panel (Sitronix **ST7365P**
controller, 320×480) to the same 8-pin JST-XH the button board already speaks.
It is the alternative to fitting an HX8357 breakout — the display firmware
detects which panel is present at boot (`tft.ino`) and drives either one.

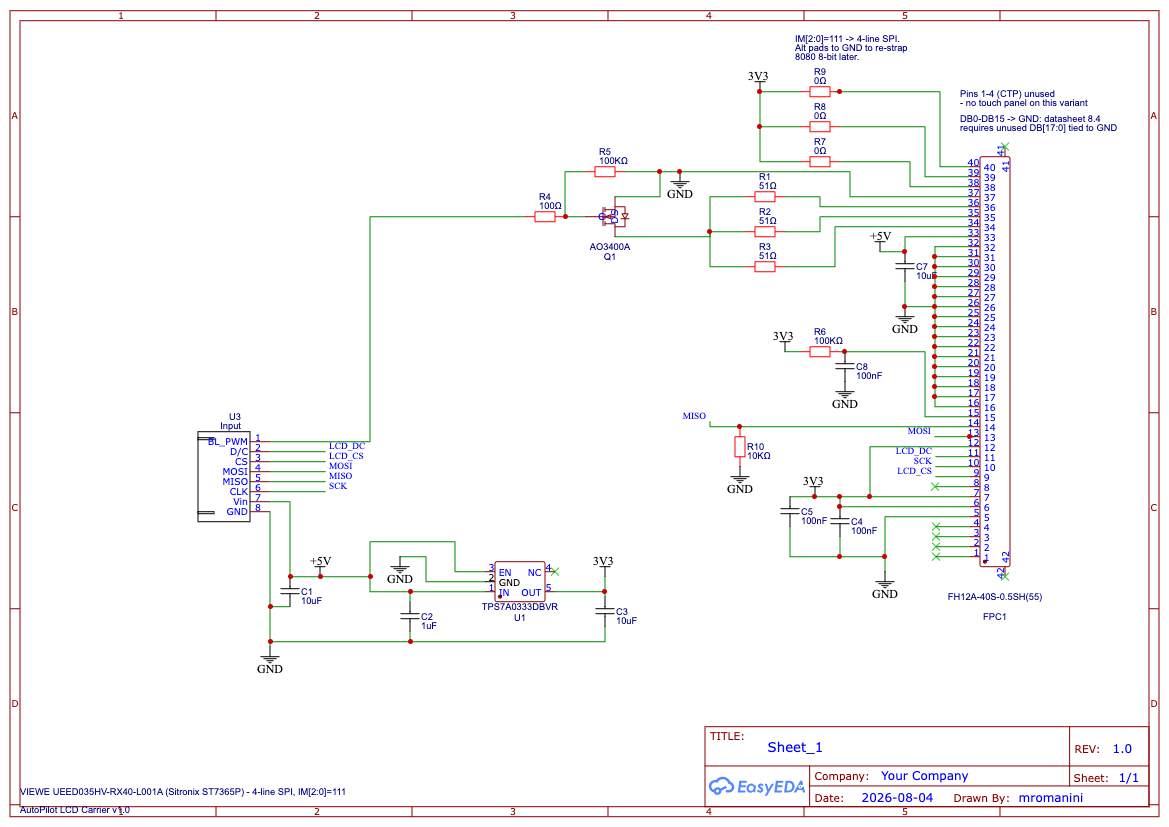
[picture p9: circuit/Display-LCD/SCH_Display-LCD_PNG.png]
LCD carrier schematic


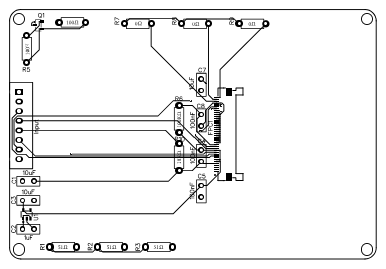
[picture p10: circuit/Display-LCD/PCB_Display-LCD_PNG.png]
LCD carrier PCB


## Components

| Ref | Part | Role |
|-----|---|---|
| **U3** | JST-XH 8-pin (**Input**) | From the button board: `BL_PWM`, `D/C`, `CS`, `MOSI`, `MISO`, `CLK`, Vin (5 V), GND |
| **FPC1** | **HRS FH12A-40S-0.5SH(55)** | 40-pin 0.5 mm FPC connector the panel's flex tail plugs into |
| **U1** | **TI TPS7A0333DBVR** | 3.3 V LDO — the panel logic runs at 3V3 while the ribbon arrives at 5 V (C1 10 µF in, C2 1 µF, C3 10 µF out) |
| **Q1** | **AO3400A** N-channel MOSFET | Low-side switch for the **backlight**, gated by `BL_PWM` (R4 100 Ω gate series, R5 100 kΩ pull-down) |
| **R1–R3** | 51 Ω | Ballast for the three backlight LED strings (FPC 34/35/36; anodes on 5 V at FPC 33) |
| **R7–R9** | 0 Ω | `IM[2:0]` strapped to 3V3 = **111 → 4-line SPI**. Alternate pads to GND re-strap the panel to 8080 8-bit later |
| **R6 / C8** | 100 kΩ / 100 nF | Power-on **reset** for the panel (FPC 15) |
| **R10** | 10 kΩ | `MISO` pull-down |
| **C4–C7** | 100 nF / 10 µF | Panel 3V3 and backlight-rail decoupling |

Only the 4-line SPI pins are wired: `CS` (9), `SCK` (10), `D/C` (11), `MOSI`
(13) and `MISO` (14). The unused parallel bus `DB[17:0]` (FPC 16–32) is tied to
**GND**, which the panel's datasheet §8.4 requires, and the four capacitive-touch
pins (FPC 1–4) are left unconnected — this panel variant has no touch layer.

---

One of the [AutoPilot circuit boards](../README.md) — that README covers how the
boards fit together and the open review items. It is the optional third board in
the display unit, fed from the [button board](../Display-Button/README.md).
Firmware: [`../../firmware/Arduino/README.md`](../../firmware/Arduino/README.md).
Enclosure: [`../../cad/display/`](../../cad/display/README.md).

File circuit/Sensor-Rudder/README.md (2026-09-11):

# Rudder sensor — `SM AP Rudder Sensor`, rev 1.0

A standalone board that reports rudder angle to the controller over Wi-Fi
(UDP 8890/8891) — the boat is wheel-steered, so the controller has no other way
to know where the rudder actually is. It is a unit on its own: one board in its
own case down by the quadrant, with nothing running to it but a 12 V pair.
Deliberately minimal — a Nano ESP32, a magnetic angle encoder, and 12 V in.

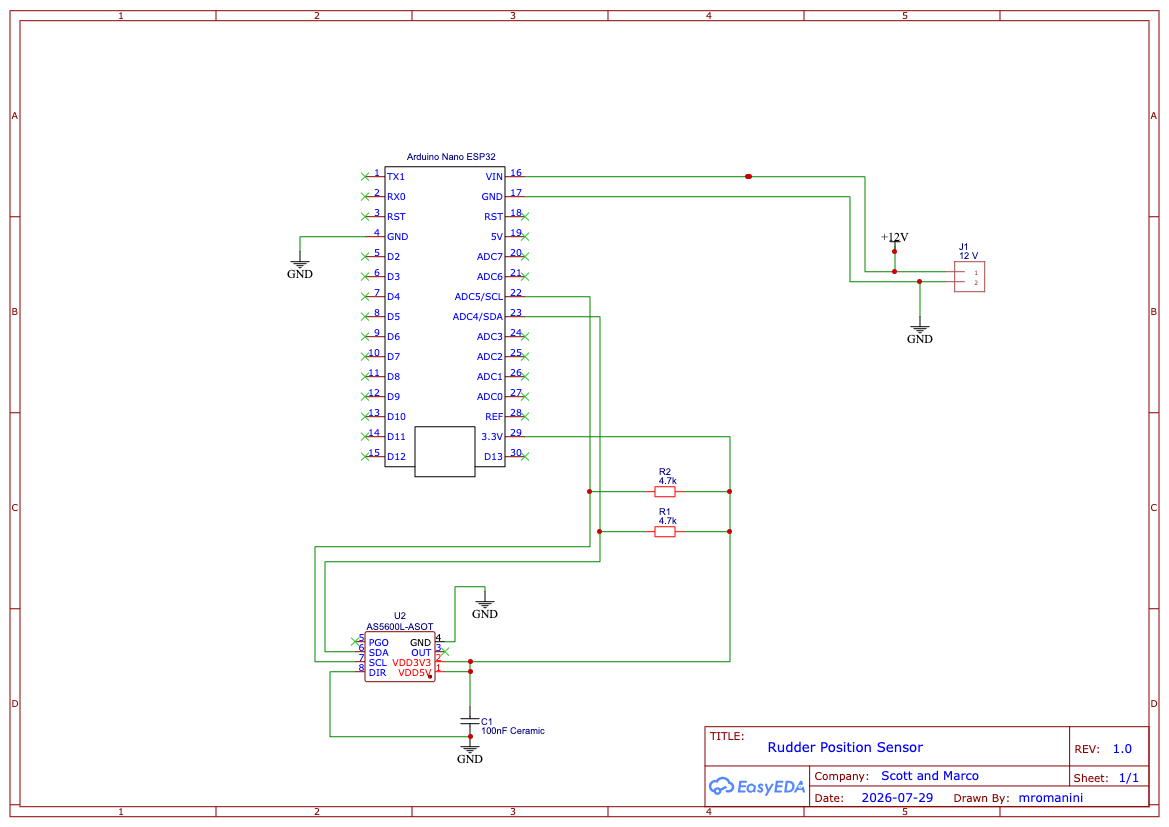
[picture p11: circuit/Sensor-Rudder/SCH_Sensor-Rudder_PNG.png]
Rudder sensor schematic


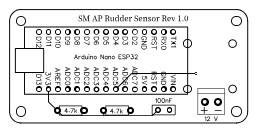
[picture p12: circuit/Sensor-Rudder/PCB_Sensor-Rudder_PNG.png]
Rudder sensor PCB


## Components

| Ref | Part | Role |
|-----|---|---|
| **U1** | **Arduino Nano ESP32** | Runs the `rudder/` sketch; joins **SoberPilot** as a station |
| **U2** | **AMS AS5600L-ASOT** (SOIC-8) | Contactless 12-bit magnetic rotary encoder — reads the angle of a magnet on the rudder stock |
| **R1 / R2** | 4.7 kΩ | I²C pull-ups on `SDA` / `SCL` to **3V3** |
| **C1** | 100 nF | AS5600L decoupling |
| **J1** | 2-pin 3.5 mm terminal block | **12 V** in, straight to the Nano's `VIN` |

Both AS5600L supply pins (`VDD5V`, `VDD3V3`) are tied to the Nano's **3V3**
pin, not 5 V — a 5 V-powered module would pull the I²C lines above what the
ESP32's 3.3 V-only GPIOs tolerate. `DIR` is tied to GND, fixing the direction of
increasing counts. The sensor sits on the Nano's dedicated `SDA`/`SCL` pins
(`ADC4/SDA`, `ADC5/SCL`); everything else on the Nano is unused.

Centring is a runtime command (`~APCMD,z$`), not a build constant, so the
zero offset can be set with the rudder physically amidships and is persisted in
NVS — see [`../../firmware/Arduino/README.md`](../../firmware/Arduino/README.md).

---

One of the [AutoPilot circuit boards](../README.md) — that README covers how the
boards fit together and the open review items. This board is a sealed one-board
unit on its own. Firmware: [`../../firmware/Arduino/README.md`](../../firmware/Arduino/README.md).
Enclosure: [`../../cad/rudder/`](../../cad/rudder/README.md).

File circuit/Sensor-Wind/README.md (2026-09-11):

# Wind sensor — `SM AP Wind Sensor`, rev 1.0

The masthead board. Same idea as the rudder sensor — a standalone Nano ESP32
joining SoberPilot and unicasting to the controller (UDP 8892/8893) — but with
three sensors on it: apparent wind angle, wind speed, and air temperature. The
long tapered outline is shaped to fit the Yachta sensor head, which is the
enclosure for this unit (see [`../../cad/wind/`](../../cad/wind/)); the only
wiring up the mast is 12 V from the masthead light circuit.

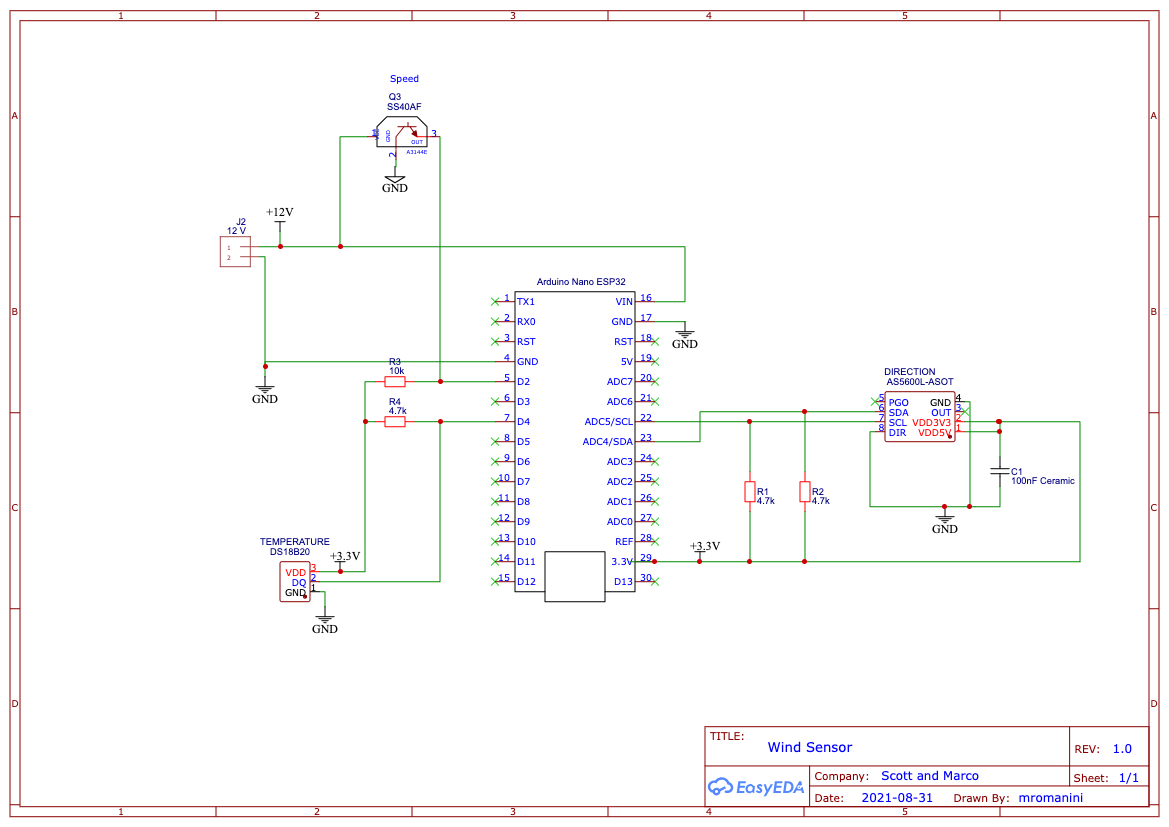
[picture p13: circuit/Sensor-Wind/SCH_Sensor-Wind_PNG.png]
Wind sensor schematic


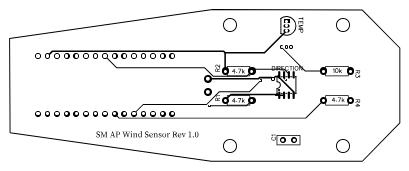
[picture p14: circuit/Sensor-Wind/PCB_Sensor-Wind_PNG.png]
Wind sensor PCB


## Components

| Ref | Part | Role |
|-----|---|---|
| **U1** | **Arduino Nano ESP32** | Runs the `wind/` sketch; joins **SoberPilot** as a station |
| **DIRECTION** | **AMS AS5600L-ASOT** (SOIC-8) | Wind **vane** angle — magnetic encoder on the vane spindle, on `SDA`/`SCL` |
| **Q3** | **Honeywell SS40AF** Hall-effect switch (A3144E footprint) | Wind **speed** — one pulse per cup-wheel magnet pass, open-collector output to `D2` |
| **TEMPERATURE** | **DS18B20** (TO-92) | Air temperature on 1-Wire |
| **R1 / R2** | 4.7 kΩ | I²C pull-ups on `SDA` / `SCL` to **3V3** |
| **R3** | 10 kΩ | Pull-up on the Hall sensor's open-collector output to **3V3** |
| **R4** | 4.7 kΩ | 1-Wire pull-up on the DS18B20 data line to **3V3** |
| **C1** | 100 nF | AS5600L decoupling |
| **J2** | 2-pin 3.5 mm terminal block | **12 V** in (masthead light circuit), to the Nano's `VIN` |

As on the rudder board, the AS5600L runs off **3V3** with `DIR` to GND. The
Hall switch is the one part fed from **12 V** (SS40AF is rated 3.8–30 V); its
open-collector output is pulled up to 3V3, so the ESP32 still only ever sees
3.3 V logic.

Pin assignments match the `wind/` sketch: cup speed on `D2`
(`WIND_SPEED_PIN`), DS18B20 on `D4` (`ONE_WIRE_PIN`), vane on the dedicated
I²C pins.

Both the vane zero and the wind-speed calibration are runtime commands
persisted in NVS, so a unit that is already up the mast never has to be
reflashed to be calibrated — see [`../../firmware/Arduino/README.md`](../../firmware/Arduino/README.md).

---

One of the [AutoPilot circuit boards](../README.md) — that README covers how the
boards fit together and the open review items. This board is a sealed one-board
unit on its own. Firmware: [`../../firmware/Arduino/README.md`](../../firmware/Arduino/README.md).
Enclosure: [`../../cad/wind/`](../../cad/wind/README.md).

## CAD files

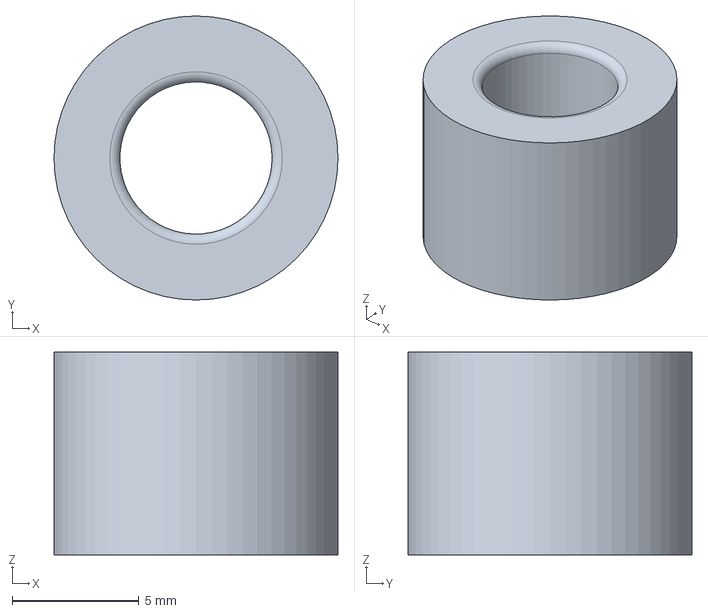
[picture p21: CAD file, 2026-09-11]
cad/common/CordGripSeal.FCStd
11.2 x 11.2 x 8.00 mm

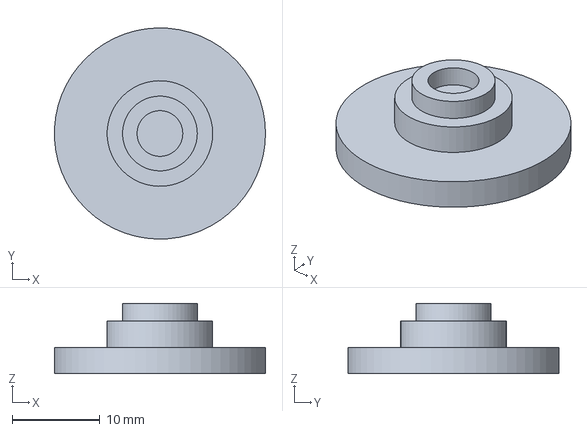
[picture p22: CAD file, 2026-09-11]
cad/rudder/TestMagnetHolder.FCStd
24.0 x 24.0 x 8.00 mm

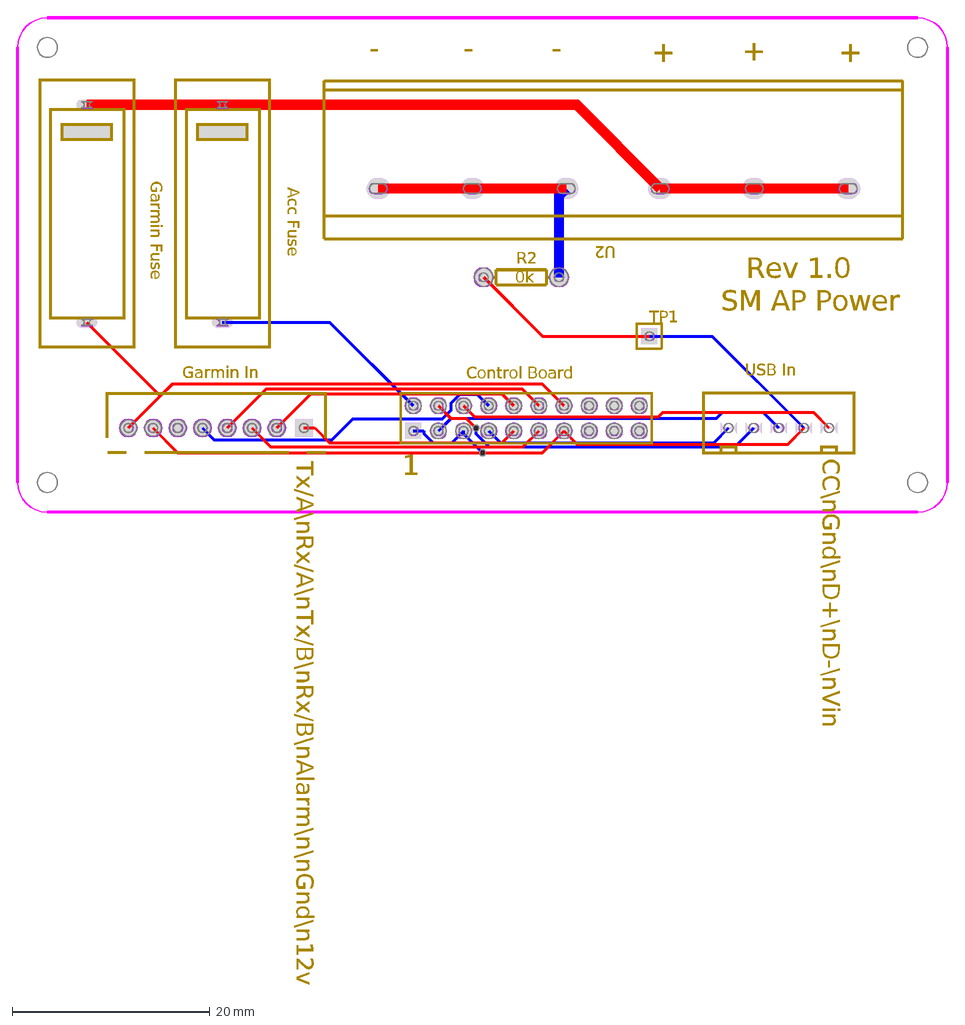
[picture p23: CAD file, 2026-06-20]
circuit/Controller-12-volt-power/PCB_Controller-12-volt-power_DXF.dxf
Tx/A\nRx/A\nTx/B\nRx/B\nAlarm\n\nGnd\n12v
CC\nGnd\nD+\nD-\nVin
SM AP Power
Rev 1.0
1
-
+
Control Board
U2
Acc Fuse
Garmin Fuse
TP1
0k
R2
Garmin In
USB In

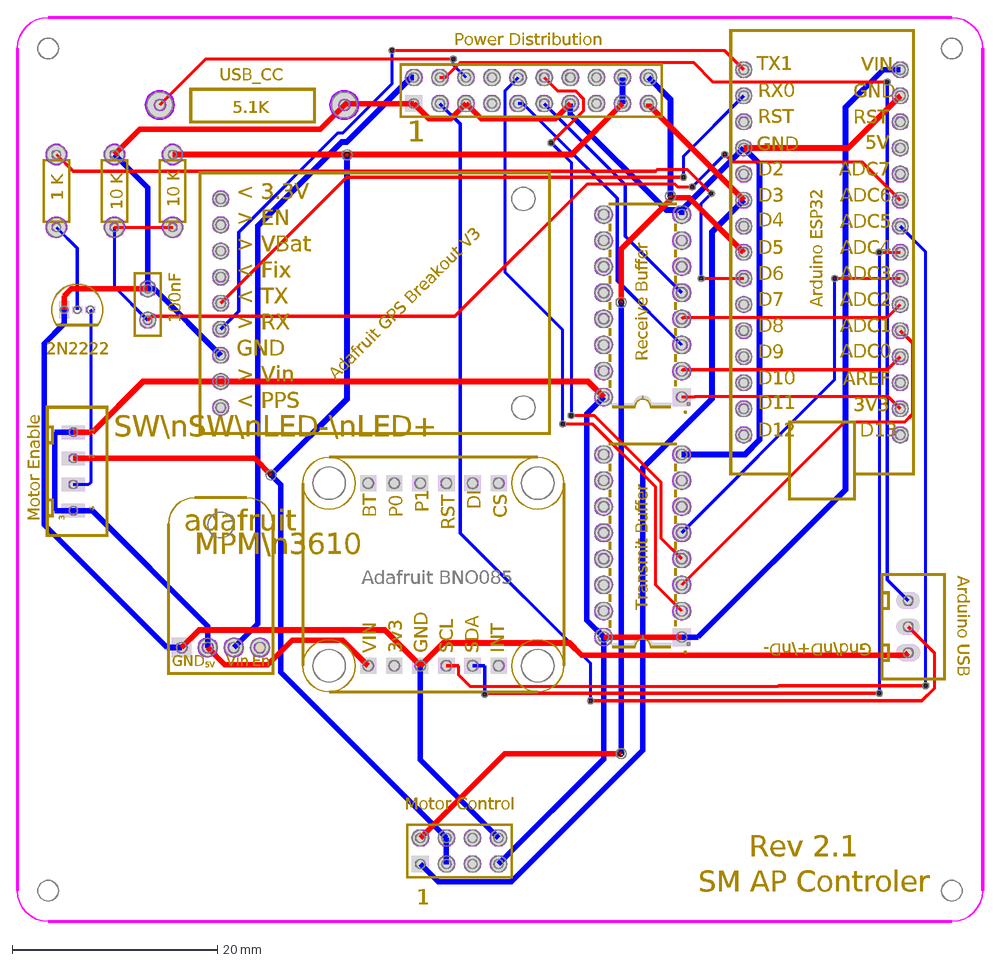
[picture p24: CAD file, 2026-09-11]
circuit/Controller/PCB_Controller_DXF.dxf
Rev 2.1
SM AP Controler
SW\nSW\nLED-\nLED+
Gnd\nD+\nD-
1
Motor Control
100nF
2N2222
Motor Enable
2
3
4
Receive Buffer
Transmit Buffer
10 K
1 K
5.1K
USB_CC
Power Distribution
Arduino ESP32
TX1
RX0
RST
GND
D2
D3
D4
D5
D6
D7
D8
D9
D10
D11
D12
D13
3V3
AREF
ADC0
ADC1
ADC2
ADC3
ADC4
ADC5
ADC6
ADC7
5V
VIN
Adafruit BNO085
3v3
SCL
SDA
INT
CS
DI
P1
P0
BT
Arduino USB
MPM\n3610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

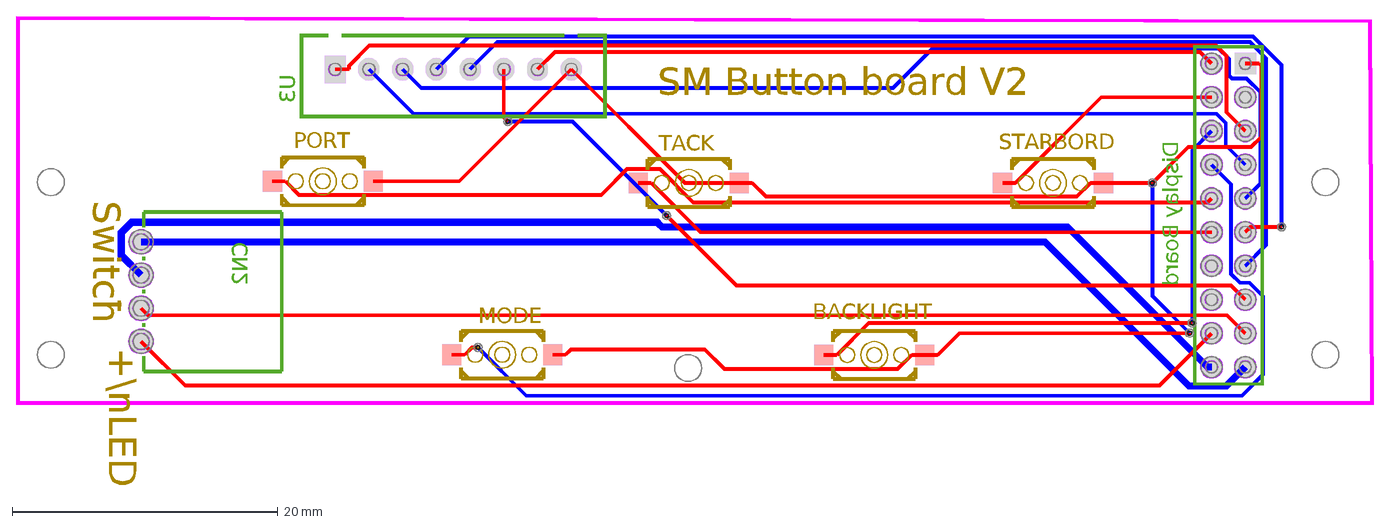
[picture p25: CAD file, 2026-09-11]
circuit/Display-Button/PCB_Display-Button_DXF.dxf
SM Button board V2
- +\nLED
Switch
CN2
U3
Display Board
BACKLIGHT
MODE
TACK
PORT
STARBORD

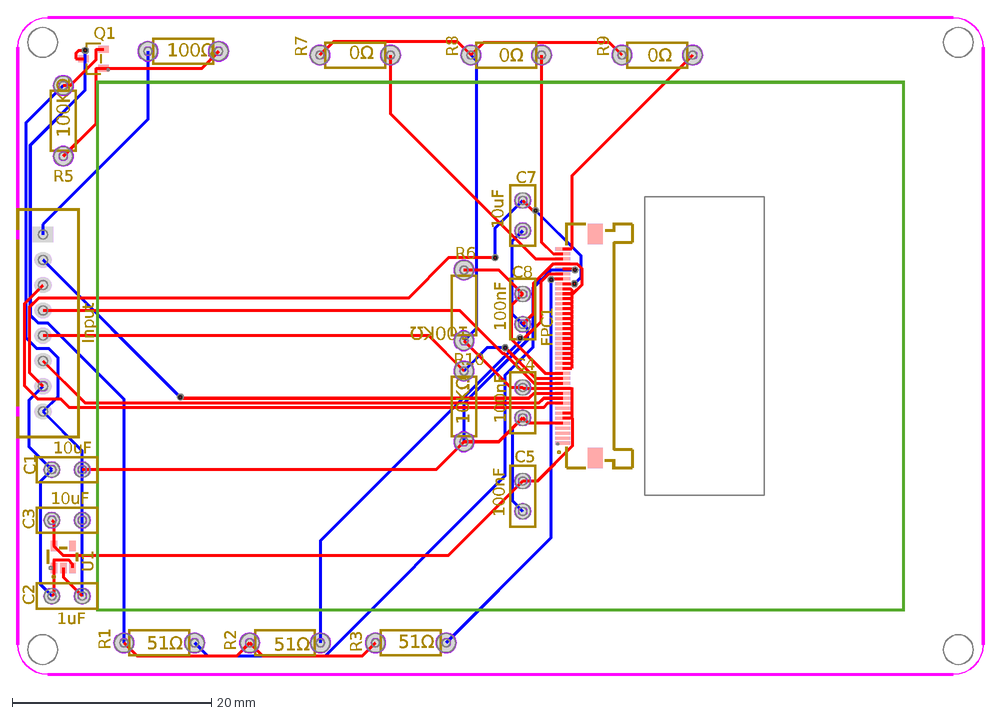
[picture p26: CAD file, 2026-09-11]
circuit/Display-LCD/PCB_Display-LCD_DXF.dxf
10uF
C1
1uF
C2
C3
100nF
C4
C5
C7
C8
FPC1
Q1
51Ω
R1
R2
R3
100Ω
100KΩ
R5
R6
0Ω
R7
R8
R9
U1
Input
10KΩ
R10

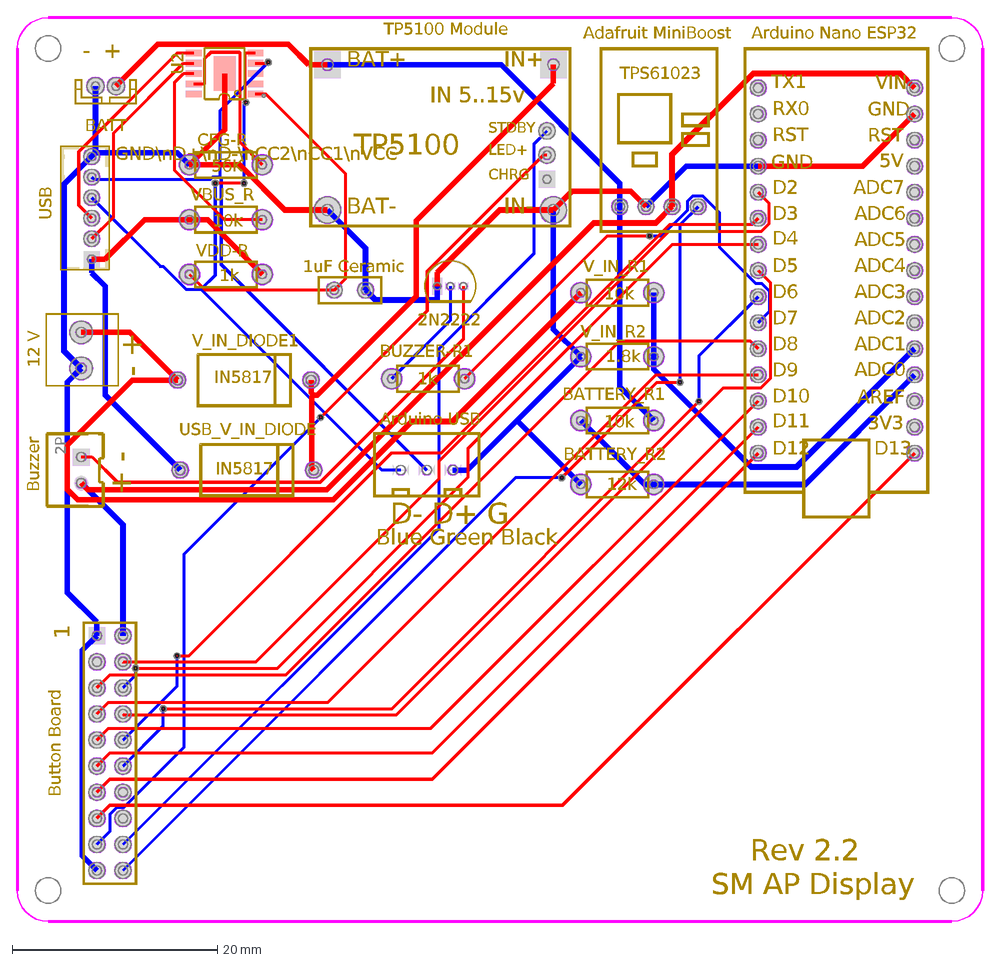
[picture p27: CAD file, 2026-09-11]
circuit/Display/PCB_Display_DXF.dxf
GND\nD+\nD-\nCC2\nCC1\nVCC
- +
1
SM AP Display
Rev 2.2
+ -
D- D+ G
Blue Green Black
10k
BATTERY_R1
12k
BATTERY_R2
1k
BUZZER-R1
56K
CFG-R
VBUS_R
VDD-R
V_IN_R1
1.8k
V_IN_R2
1uF Ceramic
12 V
USB
U2
Arduino Nano ESP32
TX1
RX0
RST
GND
D2
D3
D4
D5
D6
D7
D8
D9
D10
D11
D12
D13
3V3
AREF
ADC0
ADC1
ADC2
ADC3
ADC4
ADC5
ADC6
ADC7
5V
VIN
Adafruit MiniBoost
TPS61023
TP5100 Module
STDBY
TP5100
IN 5..15v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

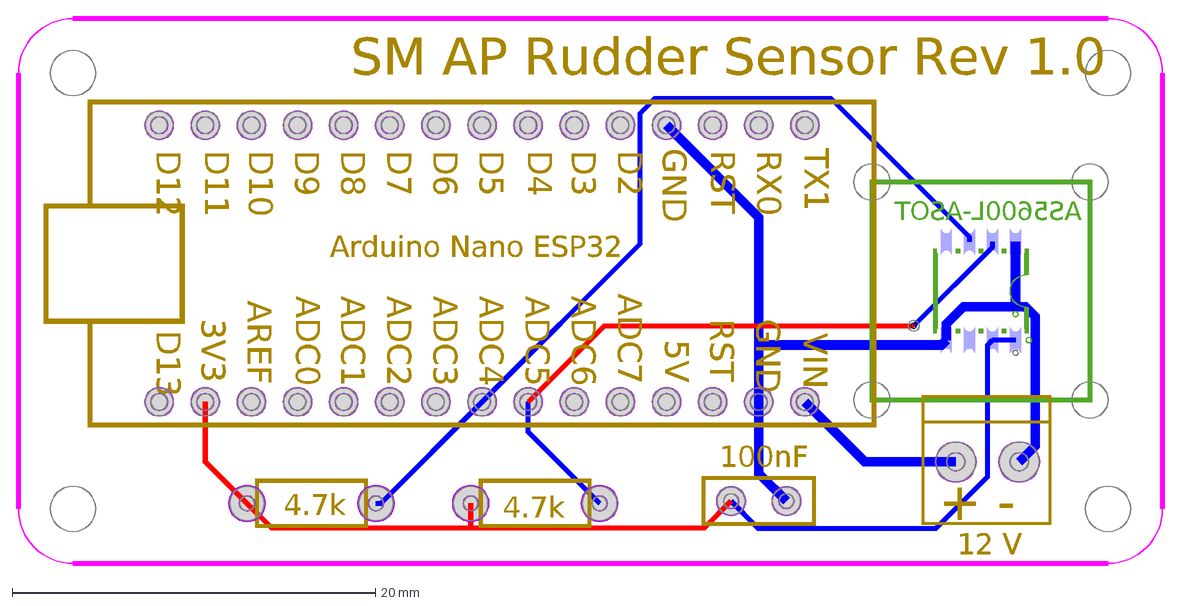
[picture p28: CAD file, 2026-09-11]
circuit/Sensor-Rudder/PCB_Sensor-Rudder_DXF.dxf
+ -
SM AP Rudder Sensor Rev 1.0
AS5600L-ASOT
100nF
12 V
4.7k
Arduino Nano ESP32
TX1
RX0
RST
GND
D2
D3
D4
D5
D6
D7
D8
D9
D10
D11
D12
D13
3V3
AREF
ADC0
ADC1
ADC2
ADC3
ADC4
ADC5
ADC6
ADC7
5V
VIN

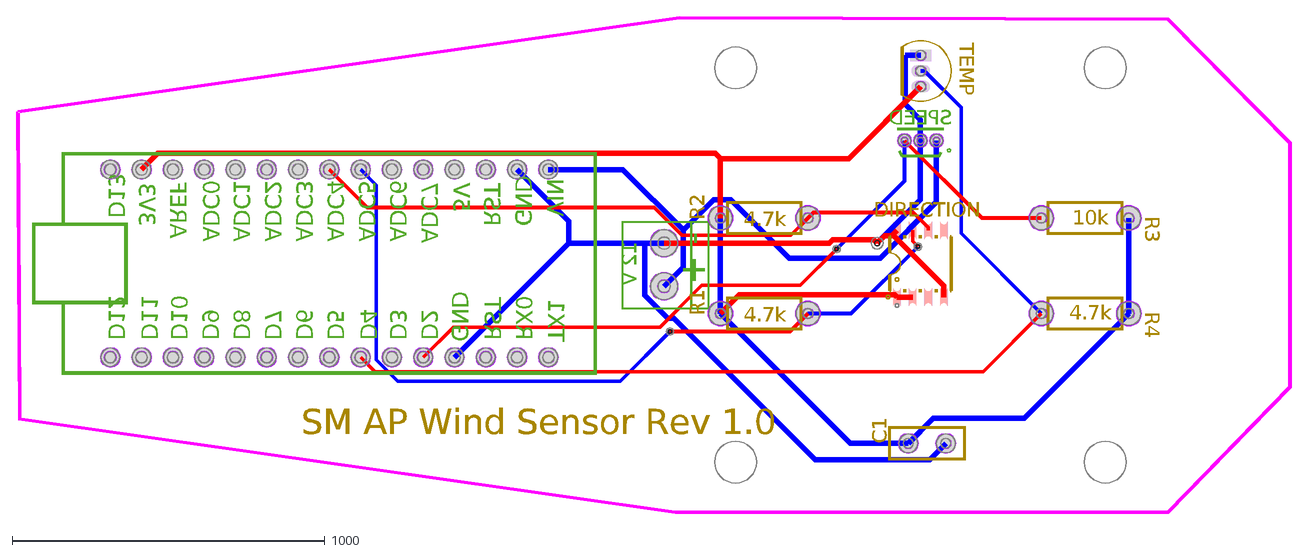
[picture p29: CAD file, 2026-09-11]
circuit/Sensor-Wind/PCB_Sensor-Wind_DXF.dxf
- +
SM AP Wind Sensor Rev 1.0
SPEED
C1
DIRECTION
12 V
4.7k
R1
R2
10k
R3
R4
TEMP
TX1
RX0
RST
GND
D2
D3
D4
D5
D6
D7
D8
D9
D10
D11
D12
D13
3V3
AREF
ADC0
ADC1
ADC2
ADC3
ADC4
ADC5
ADC6
ADC7
5V
VIN

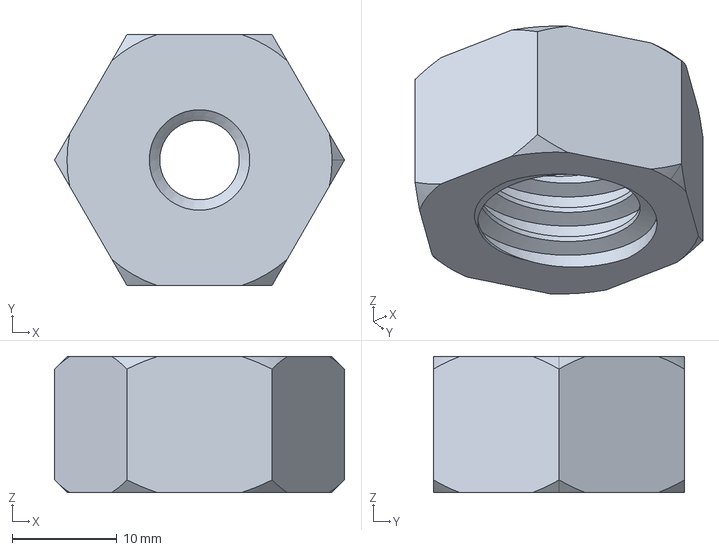
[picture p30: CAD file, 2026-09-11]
cad/common/CordGripNut.FCStd
27.7 x 24.0 x 13.0 mm

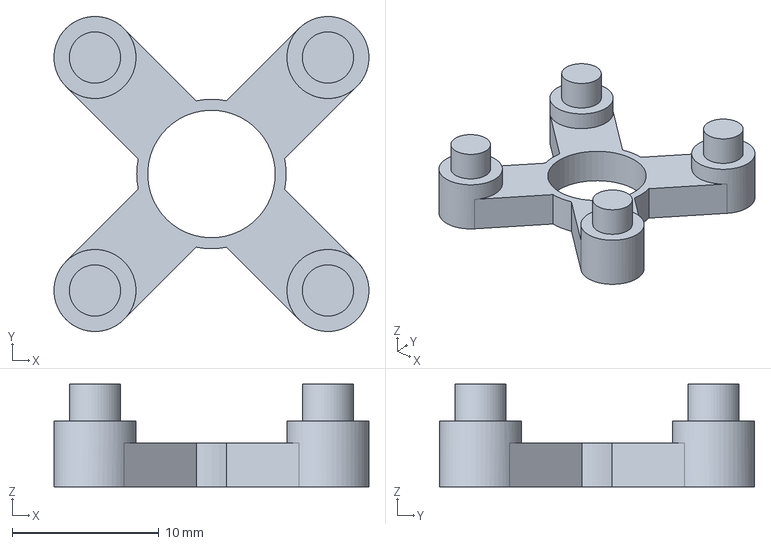
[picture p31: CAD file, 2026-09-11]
cad/rudder/TestBracket.FCStd
21.5 x 21.5 x 7.00 mm

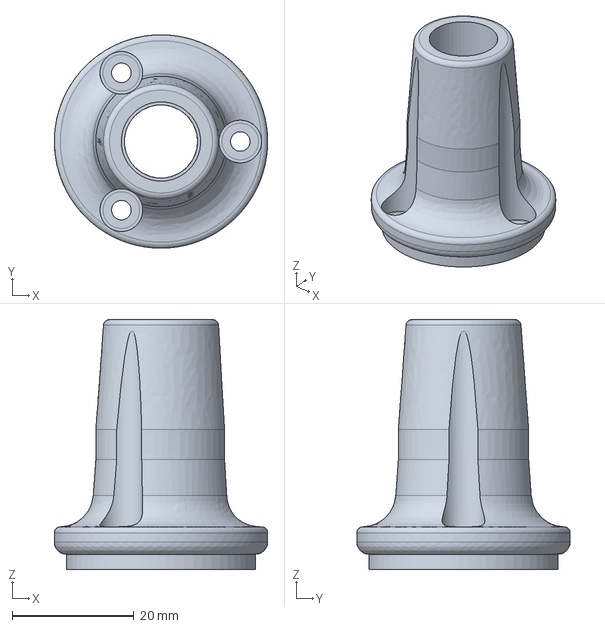
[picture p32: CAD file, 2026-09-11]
cad/wind/BottomBearingHolder.FCStd
35.0 x 35.0 x 41.0 mm

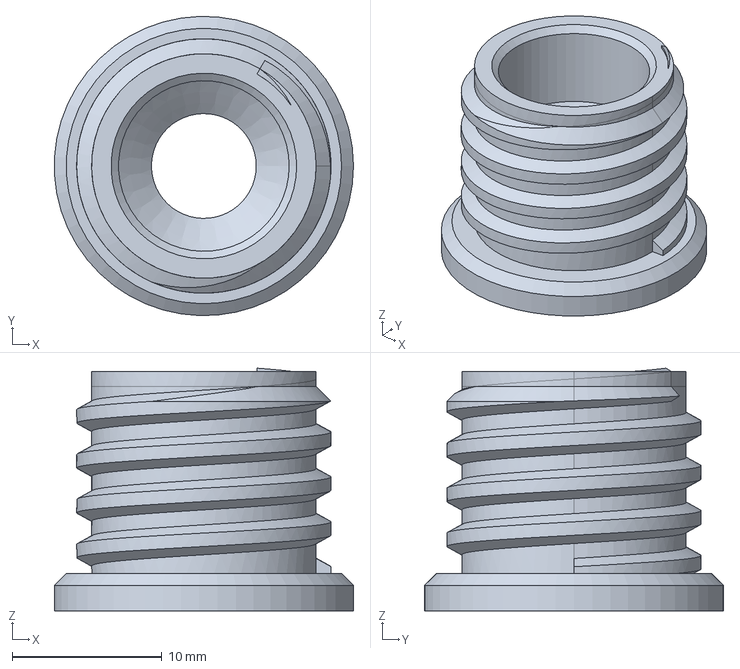
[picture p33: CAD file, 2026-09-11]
cad/common/CordGripBody.FCStd
20.0 x 20.0 x 16.2 mm

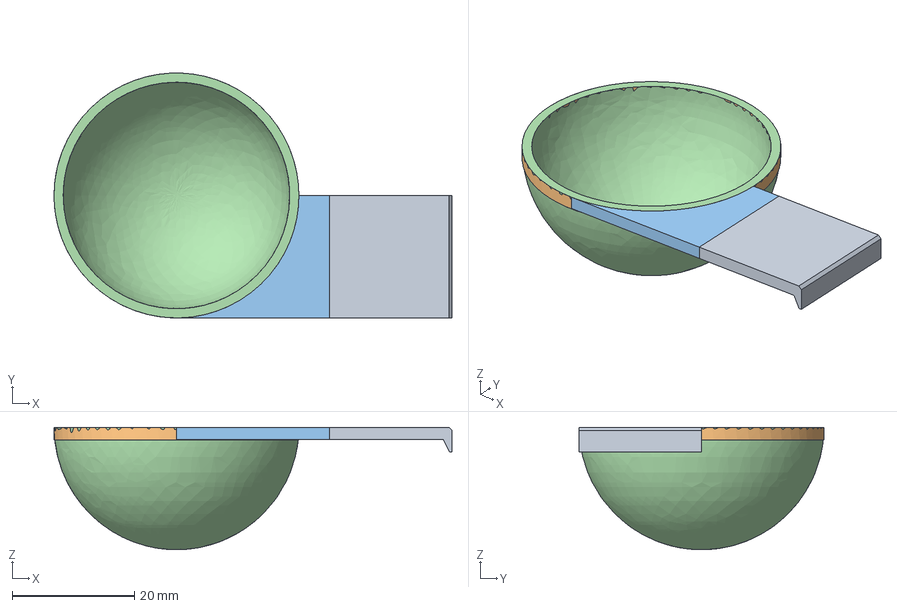
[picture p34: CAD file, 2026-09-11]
cad/wind/CupRound.FCStd
65.0 x 40.0 x 20.0 mm
CupBowl
CupArmOuter
CupArmInner
CupCollar

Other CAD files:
cad/wind/BackstayClamp.FCStd
cad/wind/TopCover.FCStd
cad/wind/BottomHousing.FCStd
cad/wind/BackstayBase.FCStd
cad/wind/BottomHousing copy.FCStd
cad/wind/CupPointed.FCStd
cad/wind/CupWheelHub.FCStd
cad/wind/MagnetHolder.FCStd
cad/wind/MastBase.FCStd
cad/wind/TopCap.FCStd
cad/wind/WindVane.FCStd
cad/wind/WindexBase.FCStd

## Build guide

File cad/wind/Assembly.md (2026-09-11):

# Wind sensor — assembly instructions

Masthead wind speed + direction sensor for the AutoPilot project. Based on the
**Yachta** wind sensor by Norbert Walter (Open Boat Projects), rebuilt around an
**Arduino Nano ESP32** so it joins the `SoberPilot` Wi-Fi like the rest of the
system.

Original instructions, which these are derived from:
<https://open-boat-projects.org/en/zusammenbauanleitung-windsensor-yachta/>

> **Read this before following any photo.**
> The photos in `assets/wind/` came from the original Yachta build and differ
> from what you are building in four ways:
>
> 1. **The cups.** The photos show the three cups and their hub printed as a
>    single piece. Ours are **three separate `CupRound` cups glued into
>    `CupWheelHub`**, which together make the part shown in the photos.
> 2. **The board.** The photos show the original ESP8266 board. Ours is the
>    Nano ESP32 board in `circuit/Sensor-Wind/`, which is longer — hence the new
>    housing.
> 3. **The housing.** `BottomHousing` and `TopCover` have been extended with a nose
>    to cover the longer board, and **the arm-tube socket has moved 47.8 mm
>    outboard along the tube axis** — see [Step 7](#step-7--standpipe-and-mast-base).
> 4. **The bearing carrier.** `BottomBearingHolder` is **5 mm longer** than the
>    original, to drop the cup wheel clear of the relocated arm socket. That
>    also means **the cup-wheel shaft screw is an M5×70, not an M5×60** — see
>    [Step 6](#step-6--cup-wheel).

---

## Contents

- [Before you start](#before-you-start)
- [Step 1 — Print](#step-1--print)
- [Step 2 — Clean and lacquer](#step-2--clean-and-lacquer)
- [Step 3 — Wind vane bearing and direction magnet](#step-3--wind-vane-bearing-and-direction-magnet)
- [Step 4 — Wind vane](#step-4--wind-vane)
- [Step 5 — Speed magnet holder and lower bearings](#step-5--speed-magnet-holder-and-lower-bearings)
- [Step 6 — Cup wheel](#step-6--cup-wheel)
- [Step 7 — Standpipe and mast base](#step-7--standpipe-and-mast-base)
- [Step 8 — Board and wiring](#step-8--board-and-wiring)
- [Step 9 — Close it up](#step-9--close-it-up)
- [Step 10 — Bench test](#step-10--bench-test)
- [Credits and licence](#credits-and-licence)

---

## Before you start

### Tools

Soldering iron and 1 mm solder · 2 mm and 2.5 mm hex keys · small Phillips
driver · 8 mm spanner (M5 nuts) · drill with a 4–5 mm bit (cable hole in the
tube) · a small hammer · tweezers · cotton buds.

### Time

An evening for assembly, but spread over **three days** because the lacquer
needs 24 h to cure and you should not handle painted parts before it has.

### The two things most likely to ruin the build

**Magnet polarity.** Both magnet installations have a polarity requirement and
both fail silently — you get plausible-looking but wrong readings. Get them
right the first time; the magnets are glued in.

**Adhesive choice.** A masthead swings through roughly −10 °C to +90 °C. Rigid
adhesives crack at that range. Use a 2-component acrylic with residual
elasticity (the original specifies **Weicon RK-1300**). Superglue is fine only
for the small captive-nut and magnet jobs called out below.

---

## Step 1 — Print

Export a mesh from each `.FCStd` in this directory — see
[README.md](README.md) for what each one is and how to export. Two parts
(`fane_support_big`, `fane_support_smal`) have no FreeCAD source and must come
out of git history or from upstream; the README gives the commands.

| Setting | Value |
|---|---|
| Material | **PETG or ASA**. Not PLA — it creeps and sags in masthead sun. |
| Colour | **White or light.** Dark filament heats enough in sun to go soft. Black PETG is explicitly unsuitable. |
| Layers | 0.2 mm |
| Walls | 3 perimeters minimum |
| Infill | 30 %+ |
| Supports | Needed for `BottomHousing` (the socket keel) and the cups |

Print **three** copies of `CupRound`. One each of everything else.

`BottomHousing` prints best rim-down (the z = 0 face on the bed), which puts the
socket keel pointing up and needs no support under the nose.

## Step 2 — Clean and lacquer

UV and salt will chalk bare PETG within a season, and layer lines wick water.

1. Wipe every part with **99 % ethanol** on a cotton bud. Skin oil ruins adhesion.
2. Spray **three thin coats** of clear lacquer that bonds to PETG without primer
   — the original specifies Dupli-Color Aerosol Art clear. Hold the can **30 cm
   away** and keep the part turning.
3. Do the **inside of the cups** too, but sparingly — pooled lacquer in a cup
   unbalances the wheel.
4. **Cure 24 h before assembling anything.**

Do not lacquer bearing seats, the pocket the board drops into, or the magnet
recesses. Mask them or wipe them clean while wet.

## Step 3 — Wind vane bearing and direction magnet

The vane turns on a **625** bearing carried in the hub on top of `TopCover`,
and its shaft carries the magnet the AS5600 reads.

1. Press the **625 bearing (16×5×5)** into the hub recess on top of `TopCover`
   until it seats on the shoulder.
2. Pass the **M5×25 countersunk screw** up through the bearing from below.
   Fit a washer and the **M5 nut** on top. Snug only — the vane must spin
   freely; you should be able to flick it and have it coast.
3. Clamp the bearing with `fane_support_smal` and **four M3×10 screws**.

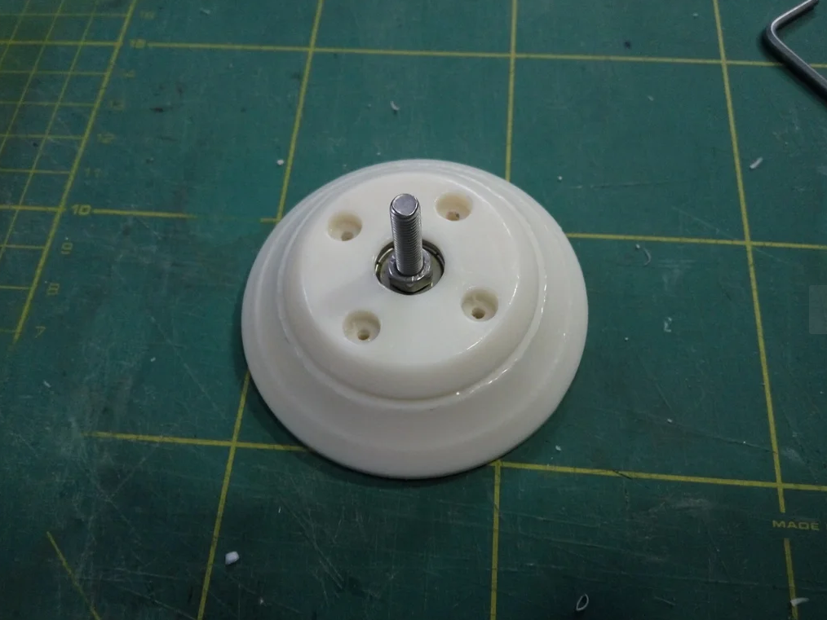
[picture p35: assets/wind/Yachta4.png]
625 bearing seated in the top_1 hub

*The 625 bearing pressed into the hub, M5×25 screw through it.*

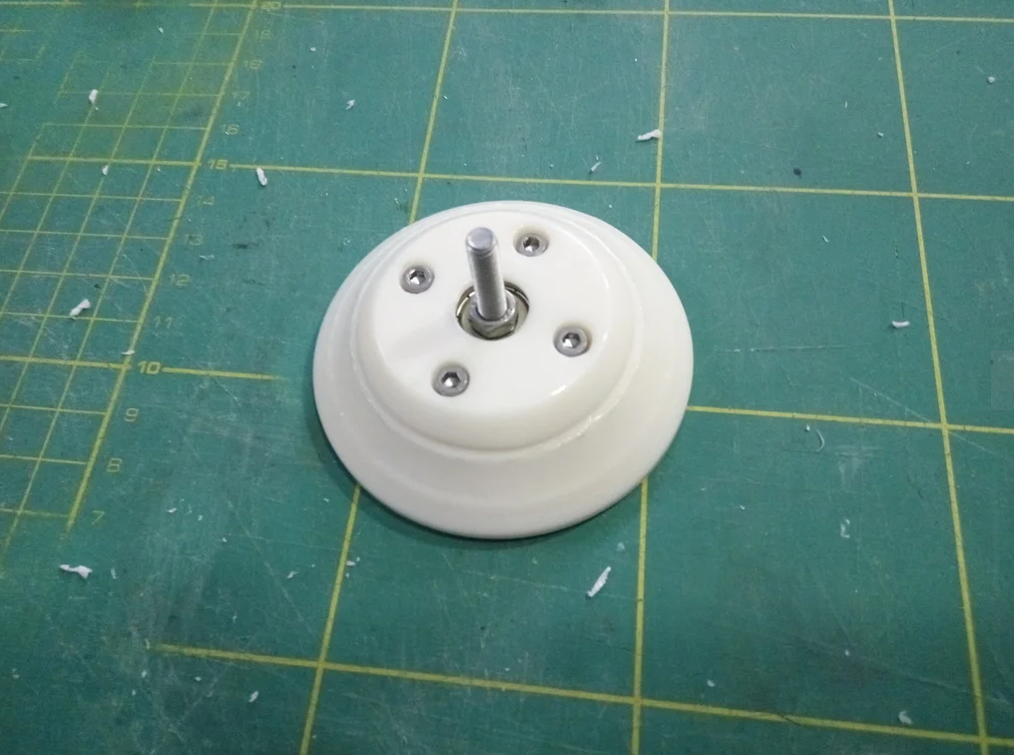
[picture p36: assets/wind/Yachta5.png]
Bearing clamped with four M3×10 screws

*Clamped down with the four M3×10 screws.*

### The direction magnet — read carefully

The AS5600 measures the **direction of a magnetic field across its face**, so
the magnet must be **diametrically magnetised** — poles on the sides, not on
the flat faces. An axially magnetised magnet of the same size will not work.

Glue the magnet to the **countersunk head of the M5×25 screw**, on the underside,
so it hangs about **1 mm above the AS5600** once `top_1` is on.

**Align the magnet's pole boundary parallel to the wind vane.** If you are a few
degrees out, that is a fixed offset you can correct in firmware — but get it
close.

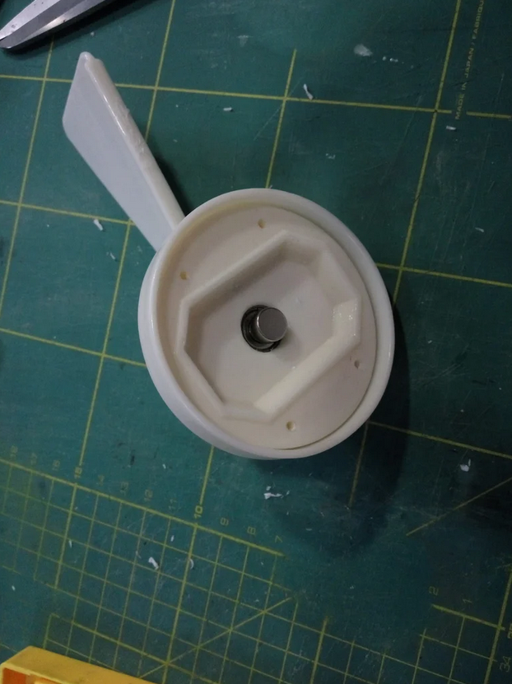
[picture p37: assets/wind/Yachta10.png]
Direction magnet on the shaft head

*The magnet glued to the screw head.*

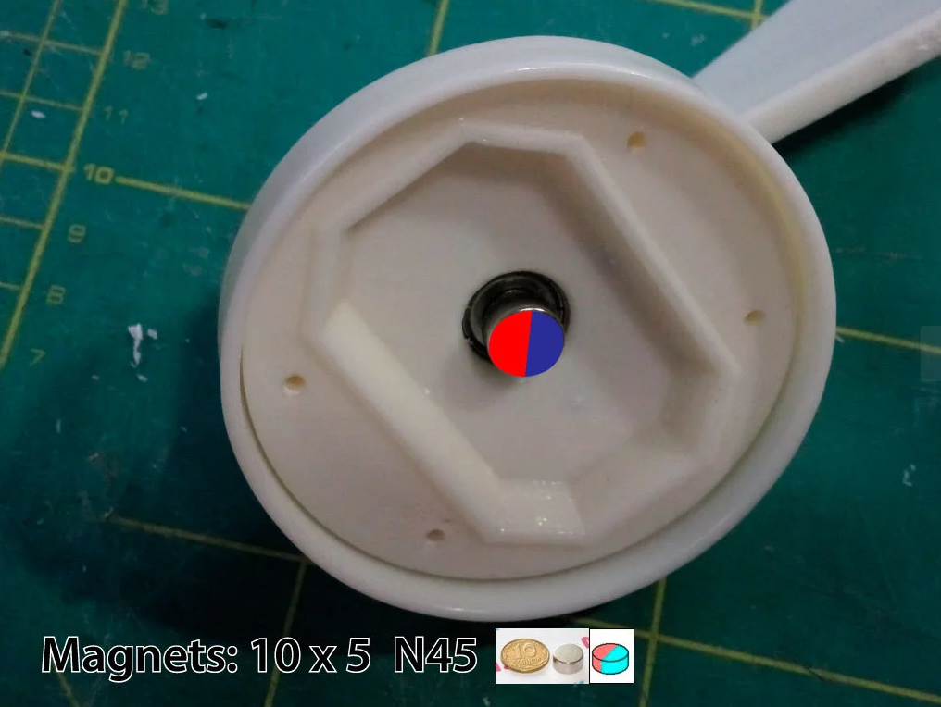
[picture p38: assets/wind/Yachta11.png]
Diametric magnetisation, poles across the diameter

*Red/blue shows the pole split — across the diameter, not top-to-bottom.*

> **Size discrepancy — pick one and note it.** The photo above is annotated
> **10×5 mm N45**, while the upstream Yachta page and its bill of materials call
> for a **5×5×5 mm square**. Any of these works *provided it is diametrically
> magnetised* and sits ~1 mm off the chip. The 10×5 disc in the photo is the
> easier one to align, because the pole boundary is visible on the rim — it is
> also what the [shopping list](README.md#bearings-fasteners-magnets) buys.

## Step 4 — Wind vane

1. Press the **M5 nut** into the recess in `WindVane` and lock it with a drop of
   superglue. Let it set before loading it.
2. Fit `fane_support_big` — the 78 mm dome — over the hub and onto the vane
   shaft.
3. Screw the vane onto the shaft.
4. Fit the **M6×60 screw** in the boss on the opposite side of the vane. This is
   the counterweight that balances the blade, not a fastener. The vane should
   sit roughly level and not fall to one side when you let it go.

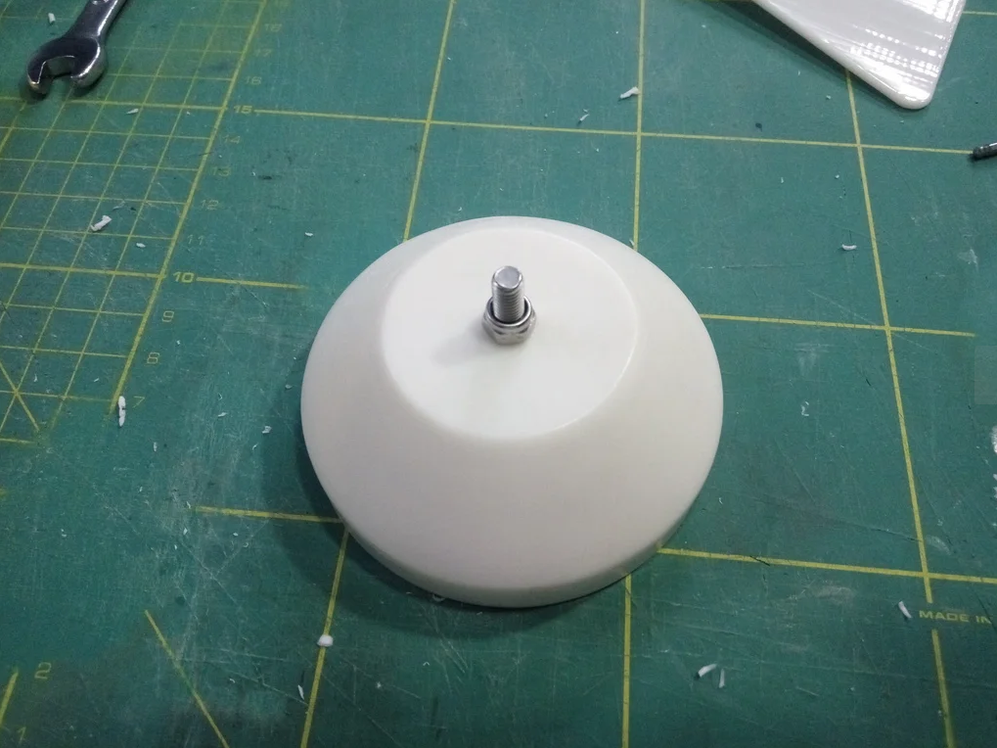
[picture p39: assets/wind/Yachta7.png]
Dome fitted over the hub

*`fane_support_big` on the hub, shaft standing proud.*

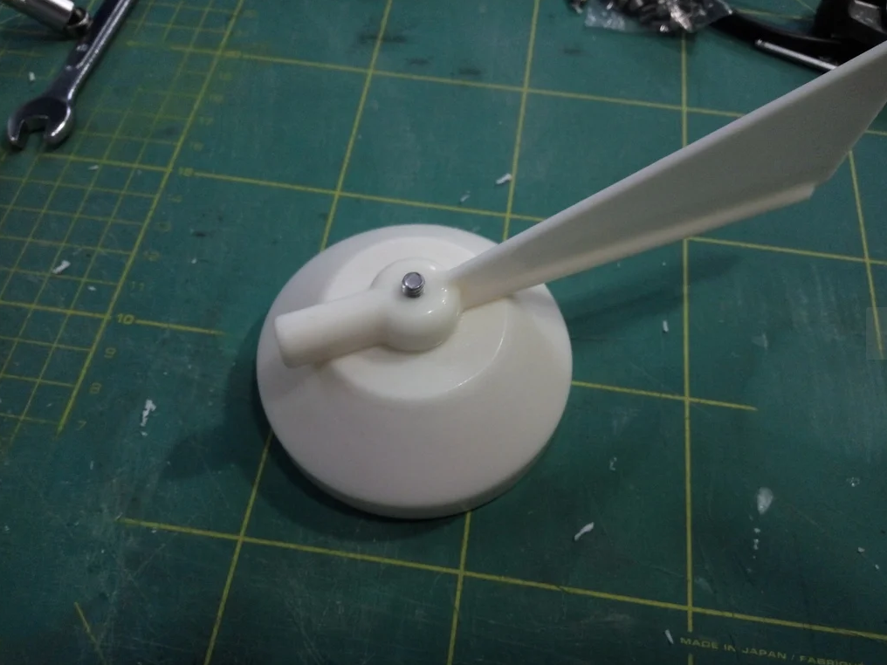
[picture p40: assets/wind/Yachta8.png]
Vane and counterweight fitted

*Vane on one side, M6×60 counterweight on the other.*

## Step 5 — Speed magnet holder and lower bearings

This is the half that measures wind **speed** — a magnet ring under the cup
wheel sweeping past the hall sensor.

> Note the carrier is **5 mm longer than the original** (41 mm, not 36 mm). The
> bearing seats, the Ø31 spigot, the Ø35 flange and the three screw holes are all
> unchanged — only the stem between the bearings was stretched, to drop the cup
> wheel clear of the relocated arm socket.

1. Press the **695 bearing (13×5×4)** into the **narrow end** of
   `BottomBearingHolder`.
2. Press a **625 bearing (16×5×5)** into the **flange end** until it seats.
   That flange end is the top in service — it plugs up into `BottomHousing`.
3. Glue the **four 5×1.5×1 mm bar magnets** into the four slots in
   `MagnetHolder`.

### Magnet polarity — the one that silently doubles your wind speed

The four magnets must **alternate**: N, S, N, S around the ring.

If you fit them all the same way the hall sensor sees **four** pulses per
revolution instead of two, and **every wind speed reads exactly double**. It
looks like a calibration problem, and it is not.

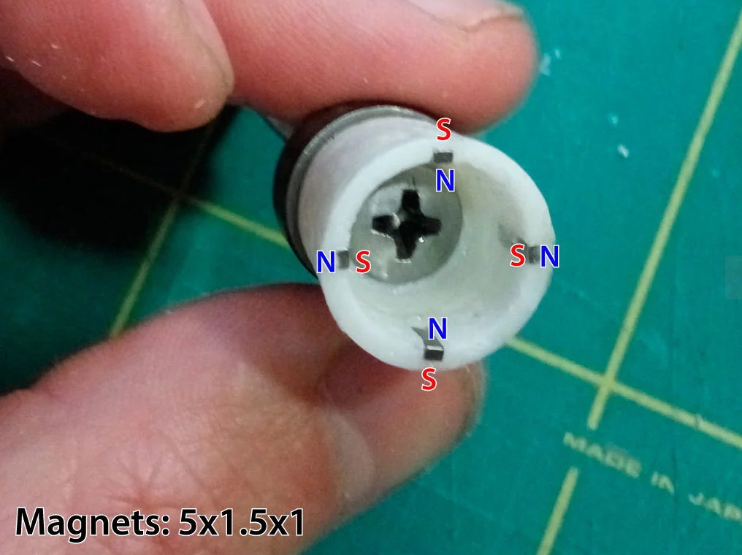
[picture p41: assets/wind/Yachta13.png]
Alternating N-S-N-S magnet polarity

*Note the alternating N/S labels around the four slots.*

Trick for gluing: tape across the **inside** of the holder, press the magnets
into the slots from the outside so they cannot jump inward, then peel the tape
once cured.

4. Thread the **M5×70 screw** up through the magnet holder and secure it from
   below with an **M5 stop nut**.
5. Slide the assembly up into the aperture in the underside of `BottomHousing`.

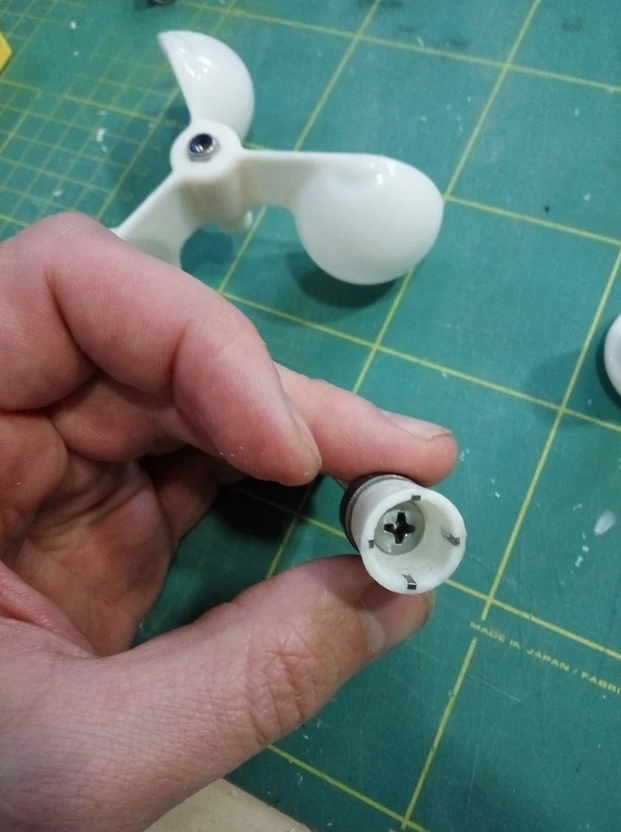
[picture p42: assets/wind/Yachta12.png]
Magnet holder on the shaft

*Magnet holder on the M5×60 screw.*

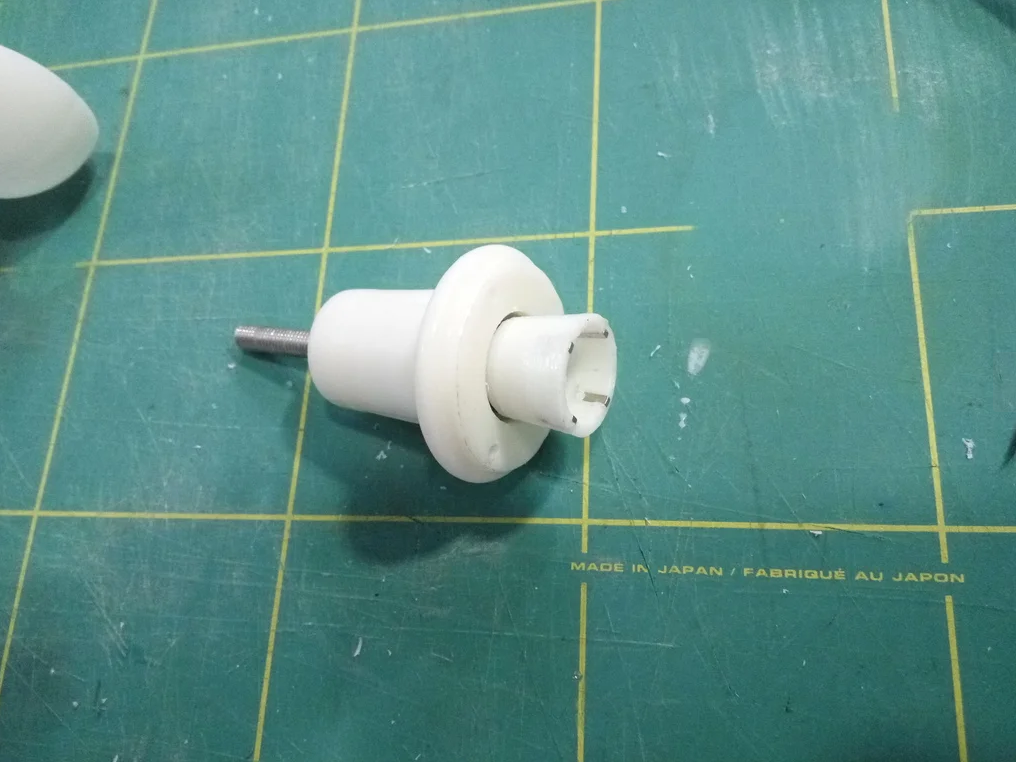
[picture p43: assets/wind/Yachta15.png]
Bearing carrier assembled

*`bot_ball_bearing` with the magnet holder through it.*

## Step 6 — Cup wheel

> **This is where our build differs from every photo below.** The photos show a
> one-piece cup wheel. Yours is four printed pieces.

1. Press the **M5 nut** into the recess in the centre of `CupWheelHub`
   and lock it with a drop of superglue.
2. **Glue the three `CupRound` cups into the hub.** Slide each arm into its
   groove from below; a gentle tap with a small hammer seats the last millimetre
   or two. Do not force a cup shell — it will crack before the arm moves.
   Use the flexible 2-component acrylic here, not superglue: these joints carry
   the whole rotating load and see the full temperature swing.
   **Check all three cups face the same way round.** A cup wheel with one cup
   reversed still spins, just badly and non-linearly.
3. Let the adhesive cure fully before spinning it up.
4. Screw the completed wheel onto the shaft from Step 5.

> ### The shaft screw is an M5×70, not the M5×60 upstream lists
> Both bearings have a 5 mm bore and must run on the **unthreaded** part of the
> shank. With the longer carrier the bearing span is 35 mm, which the old
> M5×60's 35 mm plain shank no longer covers with any margin — a bearing sitting
> on thread run-out will be sloppy and will chew its bore.
>
> Use **DIN 931 M5×70** (partially threaded: 22 mm of thread, 48 mm plain). A
> *fully* threaded M5×70 is the wrong part. Check the head still drops into the
> magnet-holder recess.
5. **Set the running clearance before you lock anything.** Tighten until the
   wheel runs without endfloat but still coasts freely when flicked. Too tight
   and it will not start in light air — which is exactly when you want it.
6. Once the feel is right, lock the thread with threadlocker.
7. **The cups now hang 5 mm lower than on the original.** Before you go up the
   mast, check what is underneath — anchor light, mast crane, backstay.

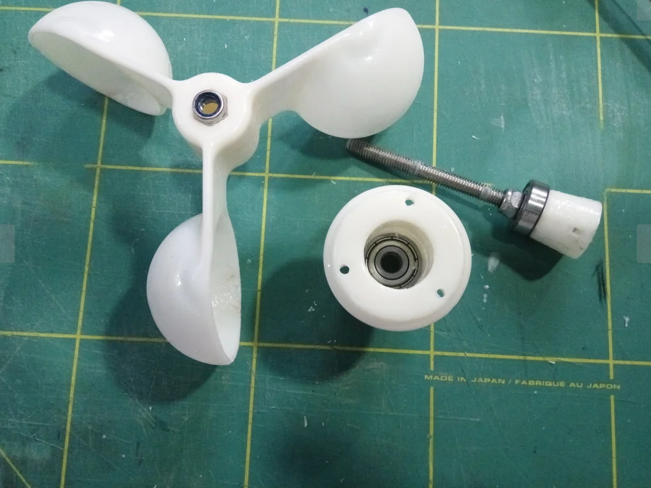
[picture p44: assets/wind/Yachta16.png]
One-piece cup wheel in the photos

*The photo shows the old one-piece part — yours is three cups plus `base_cup_wheel`.*

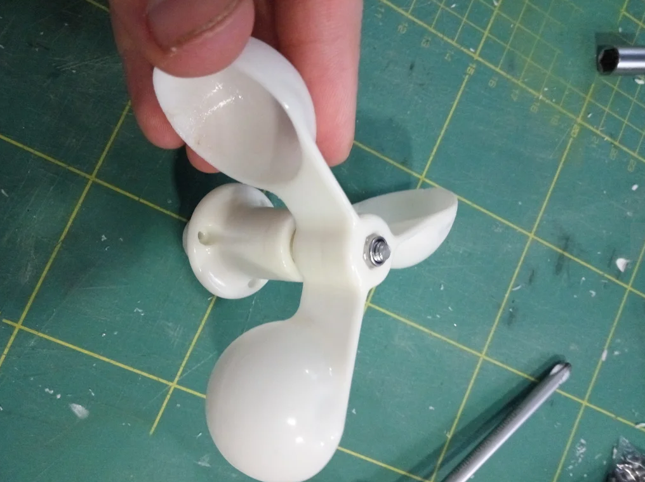
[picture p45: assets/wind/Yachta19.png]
Cup wheel mounted on the bearing carrier

*Wheel screwed down, M5 stop nut visible.*

## Step 7 — Standpipe and mast base

1. **Drill a cable hole** near the top end of the **D10×1×300 mm aluminium tube**
   and deburr it. Cable jacket against a raw drilled edge chafes through.

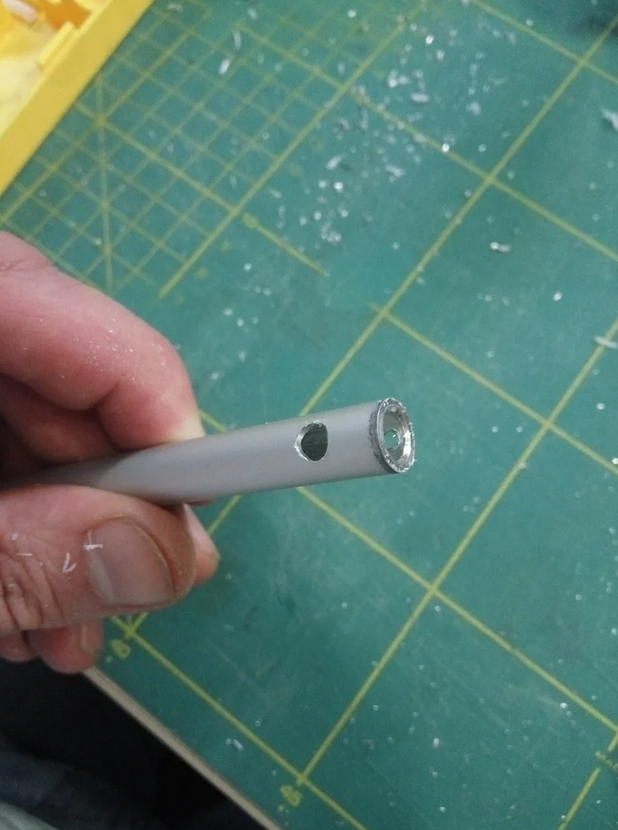
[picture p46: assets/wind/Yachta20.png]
Cable hole in the tube
   

2. Feed the 12 V cable up the tube.
3. Push the tube into the socket in `BottomHousing`.

> ### The tube is now 47.8 mm shorter than the original
> The socket was moved outboard along its own axis to make room for the Nano.
> The **angle is unchanged (20° below horizontal) and the bore is unchanged
> (Ø10)**, so the same tube and the same `MastBase` still fit — the tube
> just needs to be **47.8 mm shorter**, or the mast base moved 47.8 mm along the
> tube axis toward the sensor. Cut and deburr before you fit anything.

4. Fit the other end into `MastBase` and mount that to the masthead.

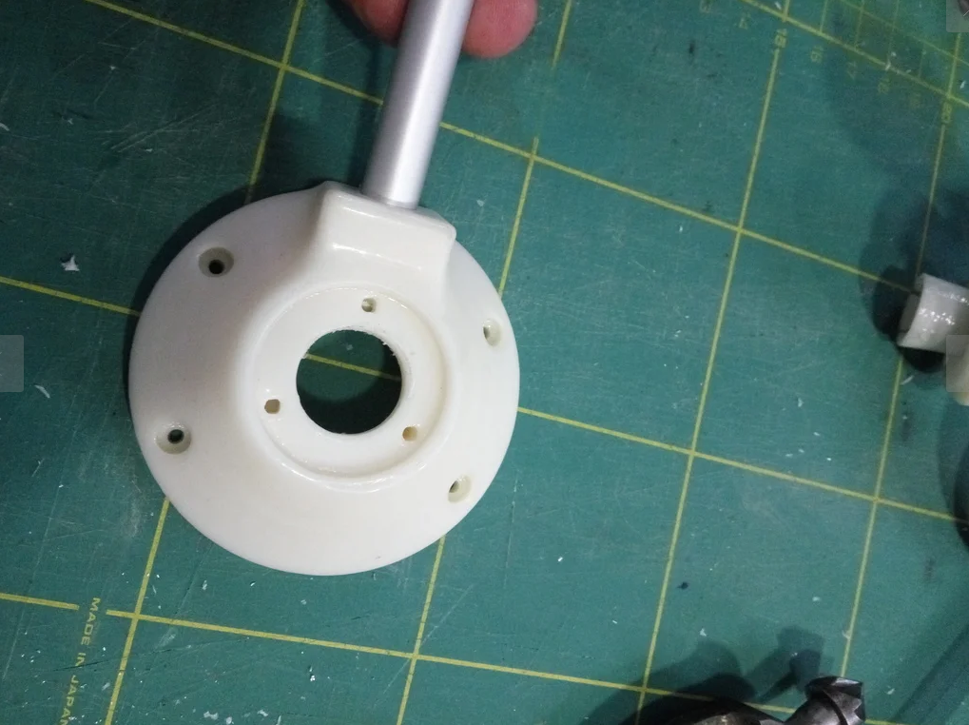
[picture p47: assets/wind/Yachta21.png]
Tube in the BottomHousing socket

*Underside of `BottomHousing` — bearing flange, centre bore, and the arm socket.*

## Step 8 — Board and wiring

The board is the one in [`circuit/Sensor-Wind/`](../../circuit/Sensor-Wind/README.md) — see
[README.md](README.md#electronics-you-will-need-to-buy) for its parts list.

1. Route the 12 V pair through into the pocket **before** the board goes in.
2. Drop the board into the pocket in `BottomHousing`. It locates on four bosses at
   ±15 / ±16 mm; the pocket has 0.4 mm clearance so it should drop in without
   force. If it binds, check for lacquer overspray in the pocket.
3. Fasten with **four M3×10 screws**.
4. Land the 12 V pair on terminal block **J2**. The cable comes up the tube,
   through the cable duct, and up the riser directly under J2.
5. **The Arduino Nano ESP32 goes in its socket on the underside of the board**,
   hanging down into the well beneath. Fit it after the board is screwed down.

### Sensor gaps — both matter

| Sensor | Gap | What it reads |
|---|---|---|
| Hall sensor (SS40AF) | **≈1 mm** from the magnet ring | wind speed |
| AS5600L | **≈1 mm** from the direction magnet | wind direction |

Too far and the reading drops out; touching and the wheel binds. Check both by
eye before closing up.

## Step 9 — Close it up

1. Check the pocket is clear of swarf and the cable is not pinched.
2. Fit `TopCover` over the board. The locating rib drops into the pocket.
3. Fasten with the four M3×10 screws at ±15 / ±25 mm, **plus the fifth screw at
   the nose tip (77.5, 0)** — that one is new and it is what keeps the long nose
   from lifting and letting water in.
4. Fit `TopCap`.

## Step 10 — Bench test

Do all of this on the bench. Nothing here is fun at the top of a mast.

1. Power up on 12 V.
2. **Spin the cups by hand.** Wind speed should rise and fall smoothly. If it
   reads roughly **double** what it should, the four speed magnets are not
   alternating — back to [Step 5](#step-5--speed-magnet-holder-and-lower-bearings).
3. **Turn the vane slowly through a full circle.** The angle should sweep 0–360°
   once, smoothly, with no jump or dead spot. A jump means the magnet is too far
   from the AS5600 or is not diametrically magnetised.
4. Point the vane at the bow mark and note the offset; correct it in firmware
   rather than by re-gluing the magnet.
5. Leave it running for an hour and check nothing heats up.

Only then take it up the mast.

---

## Credits and licence

Original design, and the assembly sequence these instructions follow:
**Norbert Walter**, [Open Boat Projects](https://open-boat-projects.org/en/zusammenbauanleitung-windsensor-yachta/)
— hardware and documentation **CC-BY-NC-SA**, firmware **GPL-3.0**.
Upstream project: <https://github.com/norbert-walter/Windsensor_Yachta>

Photographs in `assets/wind/` are from that project. This rewrite covers our
changes: the Nano ESP32 board, the extended housing, the relocated arm socket,
and the three-piece cup wheel. No images were copied from the upstream site —
everything here was already in `assets/wind/`.

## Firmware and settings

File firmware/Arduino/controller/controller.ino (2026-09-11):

#include <Wire.h>
#include <WiFi.h>
#include "esp_heap_caps.h"
#include "AutoPilot.h"

#define DEBUG_ENABLED 1
#if DEBUG_ENABLED
// Gate every debug write behind `if (Serial)` (USBCDC's operator bool = host
// connected). When USB is unplugged we must NOT enter the CDC write path: on a
// physical detach it can deadlock on an internal USB lock that setTxTimeoutMs()
// does not cover, parking whatever task called print() (e.g. command_task's
// telemetry print) until a reset. Skipping the call entirely while disconnected
// lets the controller run normally headless and resume serial when replugged.
#define DEBUG_PRINT(x) do { if (Serial) Serial.print(x); } while (0)
#define DEBUG_PRINT2(x, y) do { if (Serial) Serial.print(x, y); } while (0)
#define DEBUG_PRINTLN(x) do { if (Serial) Serial.println(x); } while (0)
#define DEBUG_PRINTLN2(x, y) do { if (Serial) Serial.println(x, y); } while (0)
#define DEBUG_PRINTF(...) do { if (Serial) Serial.printf(__VA_ARGS__); } while (0)
#else
#define DEBUG_PRINT(x)
#define DEBUG_PRINT2(x, y)
#define DEBUG_PRINTLN(x)
#define DEBUG_PRINTLN2(x, y)
#define DEBUG_PRINTF(...)
#endif

// Cross-track (XTE/BOD) steering for Garmin-sourced waypoint nav -- deferred
// Item A (.claude/docs/DeferredWork-PostSeaTrial.md). OFF by default: this is
// a compile-time-only toggle, no runtime switch. Flip to 1, rebuild, and
// reflash to enable; the feature (crosstrack.ino, plus the XTE/BOD parsing in
// garmin.ino) compiles out entirely when 0, so a disabled build carries zero
// trace of it.
#define XTE_STEERING_ENABLED 0

#if defined(ARDUINO_ARCH_ESP32)  // Check if the board is based on the ESP32 architecture (like Arduino Nano ESP32)
// Define the cores
#define CORE_0 0
#define CORE_1 1
#define MULTI_CORE true

#if MULTI_CORE
void control_task(void *pvParameters);
void command_task(void *pvParameters);
#endif
#endif

AutoPilot autoPilot = AutoPilot(&Serial);

void setup() {
  //Initialize serial
  Serial.begin(38400);
  // USB-CDC serial: never block on TX. Without this, once the TX buffer fills
  // with no host draining it (USB unplugged), the next Serial.print() blocks and
  // stalls the task that called it - which stops telemetry/steering. With a 0ms
  // timeout, prints are simply dropped while unplugged and resume cleanly when a
  // laptop is reconnected, with no reset or recompile needed.
  Serial.setTxTimeoutMs(0);
  DEBUG_PRINTLN("Start");


  Wire.begin();
  setup_wifi();
  setup_publish();
  setup_telnet();
  setup_subscribe();
  setup_rudder();
  setup_wind();
  setup_motor();
  setup_motor_enable();
  setup_compass();
  setup_gps();
  setup_garmin();
  setup_pid();
  publish_RESET();

  xTaskCreatePinnedToCore(control_task, "Task Control", 10000, NULL, 1, NULL, CORE_0);
  xTaskCreatePinnedToCore(command_task, "Task Command", 10000, NULL, 2, NULL, CORE_1);
  DEBUG_PRINTLN("Multi-core setup");

  DEBUG_PRINTLN("Setup complete");
#if DEBUG_ENABLED
  DEBUG_PRINTLN("Debug enabled");
#else
  DEBUG_PRINTLN("Debug disabled");
#endif
}

void loop() {

}

void control_task(void *pvParameters) {
  unsigned long last_mills = millis();
  unsigned long cur_mills;
  bool was_navigating = false;
  float setpoint;
  float input;
  for (;;) {  // A Task shall never return or exit.
    cur_mills = millis();
    check_compass();
    // Before anything reads navigation state this tick: the motor-enable /
    // kill switch gates it (motorenable.ino).
    check_motor_enable();

    // Advance the PID clock every loop, not just while navigating. If dt were
    // only updated inside the navigating branch it would span the entire time
    // navigation was disabled, spiking the integral the moment we re-engage.
    float diff_time = (cur_mills - last_mills) * 0.001f;
    last_mills = cur_mills;

    int autotune_state = autoPilot.getAutoTuneState();
    if (autotune_state == 2) {
      // Auto-tuning (autotune.ino) owns the wheel this tick - skip the normal
      // navigate/manual-steer path entirely until it finishes or is aborted.
      autotune_loop(diff_time);
      was_navigating = false;
      vTaskDelay(10 / portTICK_PERIOD_MS);
      continue;
    }
    if (autotune_state == 1) {
      autotune_check_ready_timeout();
    }

    bool navigating = autoPilot.isNavigationEndabled();
    if (navigating) {
      // Re-engaging navigation: clear the integral/derivative history so stale
      // windup accumulated before (or during) the disabled period can't kick
      // the rudder.
      if (!was_navigating) {
        reset_pid();
      }
      // Option 3: the inner loop always steers by the compass - it's rock
      // steady at 100 Hz, unlike raw/damped GPS course at ~1 Hz. Mode 1's
      // setpoint is the operator's compass heading; mode 2's setpoint is
      // heading_command, a magnetic-frame value that gpstracktrim.ino trims
      // slowly (see gpstracktrim.ino) to keep the GPS track on the bearing
      // (or XTE-corrected course) to the waypoint. GPS noise never reaches
      // this loop directly.
      input = autoPilot.getHeading();
      setpoint = (autoPilot.getMode() == 1) ? autoPilot.getBearing() : autoPilot.getHeadingCommand();
      // Compute PID output
      float steer_angle = pid_loop(setpoint, input, diff_time);
      motor_control_loop(steer_angle);
    } else {
      // Navigation just disengaged: freeze the wheel where it is. The PID had
      // been holding standing helm (the virtual rudder position is well away
      // from zero), while steer_angle is whatever it last was - usually 0. If
      // we steered toward it here, Disable would unwind all that standing
      // rudder in one hard multi-second turn. Adopting the current position as
      // the manual setpoint makes Disable a no-op for the wheel; telnet manual
      // steering still works from there because it sets steer_angle absolutely.
      if (was_navigating) {
        autoPilot.setSteerAngle(motor_position_degrees());
        move_motor(0);
      }
      float steer_angle = autoPilot.getSteerAngle();
      motor_control_loop(steer_angle);
    }
    was_navigating = navigating;
    vTaskDelay(10 / portTICK_PERIOD_MS);
  }
}

void command_task(void *pvParameters) {
  for (;;) {  // A Task shall never return or exit.
    check_telnet();
    check_gps();
    check_garmin();
    navsource_tick();
    gps_track_trim();
    publish_APDAT();
    //print_diagnostics();
    vTaskDelay(100 / portTICK_PERIOD_MS);
  }
}

// TEMPORARY diagnostic: prints memory/stack health once per second so we can
// see whether the controller is leaking heap (or shrinking stack) in the window
// where the display is disconnected, leading up to the telnet 'w' crash. Watch
// "free" trend down and "min"/"largest" approach zero. Remove once Bug A is found.
void print_diagnostics() {
  static uint32_t last_diag = 0;
  if (millis() - last_diag < 1000) {
    return;
  }
  last_diag = millis();
  DEBUG_PRINTF("[DIAG] heap free=%u min_ever=%u largest_block=%u | cmd_task_stack_hw=%u\n",
                (unsigned)esp_get_free_heap_size(),
                (unsigned)esp_get_minimum_free_heap_size(),
                (unsigned)heap_caps_get_largest_free_block(MALLOC_CAP_8BIT),
                (unsigned)uxTaskGetStackHighWaterMark(NULL));
}

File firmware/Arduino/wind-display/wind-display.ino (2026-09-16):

/*
 * Cockpit wind display - a bulkhead-mounted head unit that shows the masthead
 * wind as a classic analogue wind dial plus numbers.
 *
 * It is a pure listener. It joins the controller's SoberPilot Wi-Fi as a
 * station, receives the same broadcast ~APDAT telemetry the other head units
 * get, and draws the wind fields from it. It has no buttons, sends no ~APCMD,
 * and never transmits anything at all - which is why its AutoPilot mirror has
 * none of the optimistic-update machinery the button-equipped display needs
 * (see AutoPilot.h).
 *
 * Panel: the same 320x480 SPI TFT as the other head unit, either an Adafruit
 * HX8357 breakout or the VIEWE ST7365P on the LCD carrier, auto-detected at
 * boot from the MISO strap (tft.ino, identical to the display's copy). The
 * difference is orientation: this unit runs PORTRAIT (320 wide, 480 tall),
 * where the display unit runs landscape.
 */

#include "AutoPilot.h"
// Must be included here, in the main sketch file, not just where it is used:
// the Arduino build concatenates every .ino and emits generated prototypes at
// the top, so TftType has to be visible before the prototype for any .ino
// function that takes one. Same reason AutoPilot.h is included above.
#include "tft.h"
// Same reason as tft.h above: the generated prototypes are emitted before any
// of the .ino bodies, so every sketch-defined type that appears in a function
// signature has to be included here. ScreenState (screen.h) is returned by
// screen.ino's current_state(); Surface and DialRect (dial.h) are all over
// dial.ino's helpers.
#include "screen.h"
#include "dial.h"
#include <WiFi.h>

#define DEBUG_ENABLED 1
#if DEBUG_ENABLED
// Gate every debug write behind `if (Serial)` (USBCDC's operator bool = host
// connected) so we never enter the USB CDC write path while unplugged - that
// path can deadlock on a physical detach, parking the calling task until reset.
#define DEBUG_PRINT(x) do { if (Serial) Serial.print(x); } while (0)
#define DEBUG_PRINT2(x, y) do { if (Serial) Serial.print(x, y); } while (0)
#define DEBUG_PRINTLN(x) do { if (Serial) Serial.println(x); } while (0)
#define DEBUG_PRINTLN2(x, y) do { if (Serial) Serial.println(x, y); } while (0)
#define DEBUG_PRINTF(...) do { if (Serial) Serial.printf(__VA_ARGS__); } while (0)
#else
#define DEBUG_PRINT(x)
#define DEBUG_PRINT2(x, y)
#define DEBUG_PRINTLN(x)
#define DEBUG_PRINTLN2(x, y)
#define DEBUG_PRINTF(...)
#endif

// FreeRTOS task cores (the Nano ESP32 is dual-core)
#define CORE_0 0
#define CORE_1 1

void display_task(void *pvParameters);
void network_task(void *pvParameters);

AutoPilot autoPilot = AutoPilot(&Serial);

void setup() {
  Serial.begin(38400);
  // USB-CDC serial: never block on TX. Without this, once the TX buffer fills
  // with no host draining it (USB unplugged), the next Serial.print() blocks and
  // stalls the task that called it. With a 0ms timeout, prints are dropped while
  // unplugged and resume cleanly when a laptop is reconnected - no reset needed.
  Serial.setTxTimeoutMs(0);
  DEBUG_PRINTLN("Start");

  setup_screen();
  setup_wifi();
  setup_subscribe();

  // Same split as the rudder and wind sensor boards: rendering on one core,
  // anything that can block for a long time on the other. A Wi-Fi association
  // attempt inside connect_wifi() sits for up to 10 s per try, and it must not
  // be able to freeze the dial - a needle stuck at its last angle looks exactly
  // like a steady wind, which is the one failure this display must never show.
  // The screen keeps repainting from the mirror throughout, and the mirror is
  // cleared by the receive timeout, so a lost link becomes a visible "NO LINK"
  // rather than a frozen picture.
  xTaskCreatePinnedToCore(display_task, "Task Display", 10000, NULL, 1, NULL, CORE_0);
  xTaskCreatePinnedToCore(network_task, "Task Network", 10000, NULL, 2, NULL, CORE_1);

  DEBUG_PRINTLN("Setup Complete");
#ifdef DEBUG_ENABLED
  DEBUG_PRINTLN("Debug Enabled");
#else
  DEBUG_PRINTLN("Debug Disabled");
#endif
}

// ---------------------------------------------------------------------------
// serial console
//
// This unit has no buttons and no telnet, so USB is the only way to ask it
// anything. Everything here is about the panel, because the panel is the one
// part of this sketch that can fail completely silently: detection picks a
// driver, the init sequence goes out over SPI, every call returns, and the
// dial is drawn perfectly onto glass that never lights up. The log looks
// healthy throughout.
//
// Anything that touches SPI is handed to the display task as a flag rather
// than run from here - this runs on the loop task, on the other core, and two
// tasks driving one bus corrupts both. Same rule as the sensor boards' UDP
// callbacks.
// ---------------------------------------------------------------------------

static void print_console_help() {
  DEBUG_PRINTLN("--- Console ---");
  DEBUG_PRINTLN("  p  panel report");
  DEBUG_PRINTLN("  t  full-screen colour test (red/green/blue/white/black)");
  DEBUG_PRINTLN("  b  toggle backlight (D8)");
  DEBUG_PRINTLN("  w  bus test - step one signal HIGH at a time, for a DMM");
  DEBUG_PRINTLN("  i  re-initialise the panel (after reseating anything)");
  DEBUG_PRINTLN("  0  clear panel override, go back to the strap");
  DEBUG_PRINTLN("  1  force HX8357      (takes effect on reboot)");
  DEBUG_PRINTLN("  2  force ST7365P     (takes effect on reboot)");
  DEBUG_PRINTLN("  r  reboot");
}

static void handle_console(char c) {
  switch (c) {
    case 'p':
      report_panel();
      break;
    case 't':
      // Deferred to the display task - see the note above.
      request_test_pattern();
      break;
    case 'w':
      request_bus_test_step();
      break;
    case 'i':
      request_reinit();
      break;
    case 'b':
      set_backlight(!backlight_on());
      DEBUG_PRINT("Backlight: ");
      DEBUG_PRINTLN(backlight_on() ? "on" : "off");
      break;
    case '0':
    case '1':
    case '2':
      // The panel is constructed once in setup(), so the override cannot take
      // effect until the next boot - say so rather than leaving the operator
      // watching an unchanged screen and concluding the override is broken.
      set_tft_override((TftType)(c - '0'));
      DEBUG_PRINTLN("Stored. Press 'r' to reboot and apply it.");
      break;
    case 'r':
      DEBUG_PRINTLN("Rebooting...");
      delay(50);  // let the line above reach the host before USB drops
      ESP.restart();
      break;
    case '?':
    case 'h':
      print_console_help();
      break;
    default:
      break;  // newlines and stray bytes from the terminal
  }
}
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

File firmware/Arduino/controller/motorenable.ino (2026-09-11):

// Motor-enable / kill switch sense, and the lamp inside that switch.
//
// This switch is the ONLY way navigation is engaged or disengaged. It feeds the
// motor, so wiring it to navigation as well means one action does the whole
// thing - the software state can never sit there claiming to steer a motor that
// has no power, and there is exactly one place to look to answer "is it on".
//
// Nothing else may set it: the `n` command is gone from both controller command
// surfaces (subscribe.ino's ~APCMD dispatch and telnet.ino), and the display's
// enable/disable button is gone with it. ~APDAT still carries nav_enabled, so
// the displays and the plugin show the state - they just no longer author it.
//
// Circuit (circuit/Controller, U7 "Motor Enable"):
//
//        +5V ---- U7.P1 (SW)          U7.P4 (LED+) ---- +5V
//                    \  operator switch    |
//   Motor5V ---- U7.P2 (SW)          U7.P3 (LED-) ---- Q1 collector (2N2222)
//        |                                              Q1 emitter -- GND
//        +-- MOTOR_ENABLE_R1 10k --+-- A6 (ADC6)         Q1 base -- 1k -- D6
//        |                         +-- C1 100nF -- GND
//        |    MOTOR_ENABLE_R2 10k -+
//        |            |
//        |           GND
//        +-- motor header pins 3/4, POWER1 pins 17/18 (the actual motor feed)
//
// So: closing the switch puts +5 V on Motor5V, the 10k/10k divider halves it,
// and A6 reads ~2.5 V. Open, R2 pulls A6 to 0 V - the divider is what makes
// "switch open" a defined 0 rather than a floating pin. On the LED side Q1 is
// a low-side switch, so D6 HIGH saturates Q1 and lights the lamp.
//
// A6 is GPIO13 on the Nano ESP32, which is an *ADC2* channel, and ADC2 is
// shared with Wi-Fi. On the ESP32-S3 a hardware arbiter gives Wi-Fi priority;
// a read that loses the arbitration comes back invalid, and the Arduino
// wrapper turns that into a plain 0. A single sample is therefore not
// trustworthy - hence the median below, and the debounce on top of it. A
// spurious 0 is the fail-safe direction (it reads as "switch off"), so the
// filtering is about avoiding nuisance disengages, not about safety.

#define MOTOR_ENABLE_SENSE_PIN A6  // divider off Motor5V: ~2.5 V closed, 0 V open
#define MOTOR_ENABLE_LED_PIN D6    // -> 1k -> 2N2222 base; HIGH = lamp on

// Hysteresis band around the ~2.5 V "on" level and the 0 V "off" level. Wide
// on purpose: nothing lives between those two states, so the gap only has to
// swallow ADC error and the RC's edge, and a reading that lands inside it
// leaves the debounced state alone.
#define MOTOR_ENABLE_ON_MV 1500
#define MOTOR_ENABLE_OFF_MV 900

#define MOTOR_ENABLE_SAMPLES 3     // median of this many, per check - see the ADC2 note above
#define MOTOR_ENABLE_DEBOUNCE_MS 100  // a new level must hold this long before it counts

static bool motorEnableLevel = false;   // debounced switch position
static bool motorEnableCandidate = false;
static unsigned long motorEnableCandidateSince = 0;
static bool motorEnableLedOn = false;

// Written from control_task (check_motor_enable), read from command_task
// (the telnet 'p' print) - volatile for cross-task visibility, same pattern as
// lastRudderReceiveTime in rudder.ino.
static volatile uint32_t motorEnableLastMv = 0;

// Median of a few samples. Not an average: the failure mode here is an
// occasional wildly wrong reading (see the ADC2 note), and a median discards
// that outright where a mean would drag the result toward it.
static uint32_t read_motor_enable_mv() {
  uint32_t s[MOTOR_ENABLE_SAMPLES];
  for (int i = 0; i < MOTOR_ENABLE_SAMPLES; i++) {
    s[i] = analogReadMilliVolts(MOTOR_ENABLE_SENSE_PIN);
  }
  for (int i = 1; i < MOTOR_ENABLE_SAMPLES; i++) {
    uint32_t v = s[i];
    int j = i - 1;
    while (j >= 0 && s[j] > v) {
      s[j + 1] = s[j];
      j--;
    }
    s[j + 1] = v;
  }
  return s[MOTOR_ENABLE_SAMPLES / 2];
}

static void set_motor_enable_led(bool on) {
  if (on == motorEnableLedOn) {
    return;
  }
  motorEnableLedOn = on;
  digitalWrite(MOTOR_ENABLE_LED_PIN, on ? HIGH : LOW);
}

void setup_motor_enable() {
  pinMode(MOTOR_ENABLE_LED_PIN, OUTPUT);
  digitalWrite(MOTOR_ENABLE_LED_PIN, LOW);
  motorEnableLedOn = false;

  // 11 dB attenuation gives the full ~0-3.1 V input span. Any less clips well
  // below the 2.5 V the divider produces, which would read as a stuck "on".
  analogSetPinAttenuation(MOTOR_ENABLE_SENSE_PIN, ADC_11db);

  // Seed the debounced state from where the switch actually is, and leave
  // navigation alone here: check_motor_enable() below will bring it into
  // agreement on its first tick. Setting it from setup() would be doing the
  // same job twice, before the compass has produced a heading to hold.
  motorEnableLastMv = read_motor_enable_mv();
  motorEnableLevel = (motorEnableLastMv >= MOTOR_ENABLE_ON_MV);
  motorEnableCandidate = motorEnableLevel;
  motorEnableCandidateSince = millis();

  DEBUG_PRINT("Motor enable switch at startup: ");
  DEBUG_PRINT(motorEnableLevel ? "on" : "off");
  DEBUG_PRINT(" (");
  DEBUG_PRINT(motorEnableLastMv);
  DEBUG_PRINTLN(" mV)");
}
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

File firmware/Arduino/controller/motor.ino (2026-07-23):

#define MAX_MOTOR_PLUS 255
#define MAX_MOTOR_NEG 255
#define MOTOR_NEG_PIN D3
#define MOTOR_PLUS_PIN D5
#define DIRECTION_POSITIVE "starbord"
#define DIRECTION_NEGATIVE "port"
#define MIN_DEGREE_ADJUST 0.5
#define SMALL_ADJUST 3.0
#define SLOW_CHANGE 3.0
#define INV_RATE_CHANGE (1.0 / 10.0)
#define SMALL_ADJUST_RUN (SLOW_CHANGE * INV_RATE_CHANGE)
#define MILLIS_PER_DEGREE_RATE_CHANGE 100
#define MIN_MOTOR_OFF_TIME 1000
#define MILLIS_PER_DEGREE_CORRECTION 1000

// Usable rudder travel, expressed in steer-angle degrees, and the same limit in
// the integrator's "millis" units. Tune MAX_RUDDER_STEER_ANGLE to the actuator:
// it both caps how far an out-of-range command can drive the motor and bounds
// the virtual position so it can't wind up past the mechanical stop.
#define MAX_RUDDER_STEER_ANGLE 45.0
#define MAX_RUDDER_TRAVEL_MILLIS ((int)(MAX_RUDDER_STEER_ANGLE * MILLIS_PER_DEGREE_RATE_CHANGE))

unsigned long last_mills;  // millis() timestamp of the previous motor_control_loop call
int motor_mills;
int direction;
int current_mills;         // virtual rudder position accumulator (signed, clamped); not a timestamp
float current_steer;
float new_curr;
int callCount = 0;

void setup_motor() {
  pinMode(MOTOR_PLUS_PIN, OUTPUT);
  pinMode(MOTOR_NEG_PIN, OUTPUT);
  analogWrite(MOTOR_PLUS_PIN, 0);
  analogWrite(MOTOR_NEG_PIN, 0);
  current_steer = 0.0;
  last_mills = 0;
  direction = 0;
  motor_mills = 0;
  current_mills = 0;

  DEBUG_PRINTLN("Motor all setup.");
}

void move_motor(int direct) {

  analogWrite(MOTOR_PLUS_PIN, 0);
  analogWrite(MOTOR_NEG_PIN, 0);
  if (direct == 1) {
    analogWrite(MOTOR_PLUS_PIN, MAX_MOTOR_PLUS);
    direction = 1;
  } else if (direct == -1) {
    analogWrite(MOTOR_NEG_PIN, MAX_MOTOR_NEG);
    direction = -1;
  } else {
    direction = 0;
  }
  // if the direction is negative that means left/starbord but for
  // the stop time we need have it always in the future so multiply
  // run_millis by direction to always get a positive number
  // autoPilot.setMotor(millis() + (run_millis * direction), direction);
  // DEBUG_PRINT("Motor Started: ");
  // DEBUG_PRINTLN(run_millis * direction);
}

void stop_motor() {
  analogWrite(MOTOR_PLUS_PIN, 0);
  analogWrite(MOTOR_NEG_PIN, 0);


  //autoPilot.setMotor(0, 0);
  //autoPilot.setMotorLastRunTime(millis());
}

// Report the virtual rudder position in steer-angle degrees. Used on the
// navigation-disable edge (control_task) to hand the wheel over "where it is"
// instead of unwinding the standing helm the PID was holding.
float motor_position_degrees() {
  return current_mills / (float)MILLIS_PER_DEGREE_RATE_CHANGE;
}

void motor_control_loop(float new_steer_angle) {
  unsigned long cur_mills = millis();
  if (last_mills == 0) {
    last_mills = cur_mills;
    return;
  }

  int new_mills = new_steer_angle * MILLIS_PER_DEGREE_RATE_CHANGE;
  // Bound the commanded position to the rudder's physical travel so an
  // out-of-range steer command doesn't drive the motor against a stop forever.
  if (new_mills > MAX_RUDDER_TRAVEL_MILLIS) {
    new_mills = MAX_RUDDER_TRAVEL_MILLIS;
  } else if (new_mills < -MAX_RUDDER_TRAVEL_MILLIS) {
    new_mills = -MAX_RUDDER_TRAVEL_MILLIS;
  }
  // Unsigned subtraction is rollover-safe across the millis() wrap; the per-loop
  // elapsed time is small, so casting the result to int for the direction multiply
  // is safe.
  int diff_m = (int)(cur_mills - last_mills);
  last_mills = cur_mills;
  current_mills += diff_m * direction;
  // Clamp the virtual rudder position to the same travel limit. Without this it
  // integrates past the mechanical stop and then lags on reversal while it
  // "unwinds" phantom travel that the rudder never actually had.
  if (current_mills > MAX_RUDDER_TRAVEL_MILLIS) {
    current_mills = MAX_RUDDER_TRAVEL_MILLIS;
  } else if (current_mills < -MAX_RUDDER_TRAVEL_MILLIS) {
    current_mills = -MAX_RUDDER_TRAVEL_MILLIS;
  }
  if (callCount >= 100) {
    callCount = 0;
    // char buffer[100];
    // sprintf(buffer, "cur %d, new_mils, %d \n", current_mills, new_mills);
    // DEBUG_PRINT(buffer);
  } else {
    callCount++;
  }
  if (abs(current_mills - new_mills) < 100) {
    move_motor(0);
    //DEBUG_PRINTLN("move_motort(0)");
  } else {
    if (new_mills < current_mills) {
      move_motor(-1);
      //DEBUG_PRINTLN("move_motor(-1)");
    }  
    if (new_mills > current_mills) {
      move_motor(1);
      //DEBUG_PRINTLN("move_motor(1)");
    }  
  }
}

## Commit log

2023-07-03 adding mostly working code, something is wrong with the wifi
    [AutoPilot.cpp, AutoPilot.h, button.ino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]
2023-07-03 fixing wifi issue, it was a collision with the PCF board not having Wire initialized
    [button.ino, wifi.ino]
2023-07-04 moving auto-pilot arduino code so we can put other things in here
2023-07-04 adding calibrate artuino app and the pypilot app
    [babel.cfg]
2023-07-21 Fixing (I hope) the memory thingy
    [button.ino, compass.ino, display.ino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]
2023-07-22 fixing an issue when we lose fix we should stop navigting
    [AutoPilot.cpp]
2023-07-27 fixing gps which was missing sentences
    [AutoPilot.cpp, display.ino, gps.ino]
2023-08-15 Added motor control
2023-08-16 adding fixes for Nan, hopefully
    [AutoPilot.cpp, display.ino, wifi.ino]
2023-08-24 resetting the calibration
2024-01-06 Moved motor plus pin
2024-03-04 Pid test
2024-05-27 finishing display and removing raspberryPi since we are using Orange Pi now
    [babel.cfg]
2024-05-29 making an LED flash so we know we have connection
2024-05-30 making led flash every 5 sends
2024-06-13 tweaking the buttons so they do not beep if they are disabled and fine tuning the volt meter
2024-06-19 adding circuits and PCBs
    [PCB-Button_LED.dxf, PCB-Button_LED_Autorouter.dsn, PCB-Display-Autorouter.dsn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]
2024-06-26 Adding support for ESP32 even though the librariies do not support it
2024-07-02 Adding support for ESP32 even though it does not work yet
    [AutoPilot.cpp, AutoPilot.h, controller.ino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]
2024-07-03 Fixing display to not show anything if it stopped receiving
    [AutoPilot.cpp, AutoPilot.h, controller.ino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]
2024-07-15 fixing for new improce boards
    [AutoPilot.cpp, AutoPilot.h, command.ino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]
2024-07-16 fixing the dislay to work with a controller using an ESP32 rather than a 33 IoT where we have a real telnet client
    [button.ino, command.ino, screen.ino]
2024-07-21 making controller work on EPS32, that is making AutoPilot Class thread safe
2024-07-26 fixing telnet print command
    [command.ino, controller.ino]
2024-07-27 diabling debug and fixing OOM issue with date
    [display.ino, screen.ino]
2024-07-30 adding pid controller
2024-07-31 adding all arduino libraries I have wather i use them or not.
2024-08-01 Our PID controller
2024-09-18 Making ad-hock network and using the new IMU
2025-04-16 disabling the receive LED
2025-07-11 Refactor: Use GFXcanvas1 for display_destination to reduce memory
    Changed GFXcanvas16 to GFXcanvas1 for the destination_value_canvas
    in the display_destination function. This significantly reduces the
    memory required by this canvas from ~13.6KB to ~0.85KB.
    Updated canvas fill and text color calls to use 0/1 indices
    appropriate for a 1-bit canvas. Modified the final draw call
    to use tft.drawBitmap with the original foreground and background
    colors, ensuring visual output remains consistent.
    This change aims to resolve intermittent hangs potentially caused by
    memory exhaustion when allocating the larger GFXcanvas16.
    [screen.ino]
2025-07-11 Refactor: Convert all GFXcanvas16 to GFXcanvas1 in display functions
    I've updated all remaining display_* functions in screen.ino to use
    GFXcanvas1 instead of GFXcanvas16. This includes:
    - display_speed
    - display_heading
    - display_pitch
    - display_roll
    - display_stability
    - display_mode (I also fixed a typo 'disbled' to 'disabled')
    - display_bearing
    - display_bearing_correction
    - display_volts
    - display_distance
    - display_course
    - display_location_lat
    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
    [screen.ino]
2025-07-12 Fix: Implement Wi-Fi reconnection logic for display unit
    Previously, the display unit would only attempt to restart its UDP listener
    if UDP packets were not received for a period, without checking or
    attempting to re-establish the underlying Wi-Fi connection.
    This change introduces:
    1. A new function `ensure_wifi_connected()` in `wifi.ino`. This function
    checks the Wi-Fi status. If not connected, it disconnects cleanly
    and then attempts to reconnect to the configured SSID with multiple
    retries and timeouts.
    2. Modification to `subscribe.ino` such that when a UDP receive timeout
    occurs and the reconnect interval has passed, it now calls
    `ensure_wifi_connected()`. Only if Wi-Fi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
    [subscribe.ino, wifi.ino]
2025-07-18 Fix display initialization for ESP32 and add SPI pin verification
    [screen.ino]
2025-07-18 feat: Configure custom SPI pins for ESP32
    This change allows you to specify custom SPI pins for the ESP32 by defining them at the top of the `screen.ino` file.
    I also updated the `vspi->begin()` call to use these new pin definitions.
2025-08-18 fixing motor
2025-08-30 resetting correction after re-enabling
    [AutoPilot.cpp]
2025-08-31 Working auto pilot but the heading is going the wrong way
    [compass.ino, publish.ino]
2025-08-31 Reverse plus and minus pins
    [motor.ino]
2026-05-26 mskimng display work with ESP32
2026-06-13 Fixing many many errors.. thanks to Claude
    [AutoPilot.cpp, AutoPilot.h, button.ino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]
2026-06-19 fixing display to not show bearing if disabled
    [AutoPilot.cpp, AutoPilot.h, screen.ino]
2026-06-19 Add autopilot_pi OpenCPN plugin (phases 1-4)
    New plugin at opencpn_plugin/autopilot_pi/ that talks to the AutoPilot
    controller over the existing UDP protocol:
    - AutoPilotLink: wxDatagramSocket receive on 0.0.0.0:8888, 250ms poll,
    parses ~APDAT telegrams into AutoPilotState, sends ~APCMD commands
    unicast to 10.20.1.1:8889 (mode, nav enable, heading adjust, waypoint)
    - AutoPilotPanel: dockable AUI wxPanel mirroring the physical display
    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
2026-06-20 OpenCPN plugin: UI polish, bearing fixes, Set WP, toolbar icon
    Panel / UI:
    - Restructured layout: narrower Date/Time bar (213px), Send WP → Set WP
    button (107px, with padding gaps) in the bottom-right corner
    - Single button row: Mode · <<10 · <1 · 1> · 10>> · Enable/Disable
    - Caption pill fonts +1pt larger across all data boxes
    - Bearing/correction now hidden unless connected AND nav enabled
    (matches Arduino display fix in e79203b)
    - Dynamic destination font: 17pt in mode 1, 12pt in mode 2
    - Panel size snapped to content on every open via direct SetClientSize()
    on the wxAuiFloatingFrame, bypassing stale AUI perspective
    AutoPilotLink:
    - SendMode() mode 1→2: compute bearing-to-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
2026-06-20 OpenCPN plugin: add Follow checkbox for automatic route waypoint tracking
    Adds a Follow checkbox next to the Set WP button. When checked,
    SetNavigateTarget auto-sends a waypoint command whenever OpenCPN
    advances the active route leg, so the autopilot tracks the full
    route without manual intervention.
    Also trims the bottom bar: Time box replaces Date/Time (shows H:MM
    centered with GPS fix indicator), Set WP button narrowed, Follow
    checkbox fills remaining space.
2026-06-20 navigator: add from-scratch setup guide for OrangePi and RPi 4
    - Complete step-by-step instructions covering both platforms: SD flash,
    first boot, Node.js/git/Claude Code bootstrap, then Claude Code follows
    the README to finish the rest
    - Check in the three config files (udev rules, wifi-keepalive service) so
    setup steps can cp them from the repo rather than recreating by hand
    - Document RPi 4 OpenGL enable step; note OrangePi must leave it off
    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
2026-06-20 adding all the circuit diagrams
    [PCB-Button_LED.dxf, PCB-Button_LED_Autorouter.dsn, PCB-Display-Autorouter.dsn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]
2026-06-24 navigator: fix screen blanking on RPi 4, disable all screen lockers
    DPMS doesn't work on the RPi 4 vc4 driver — the kernel never forwards
    the signal to the monitor. Replace DPMS with a screen-blank.sh script
    that polls xprintidle and toggles HDMI-1 via xrandr. Also kill
    xfce4-screensaver entirely (disabling its lock settings wasn't enough),
    suppress the Display Settings popup on wake, and configure logind to
    never lock or suspend.
2026-06-25 navigator: use keyboard-only idle detection for screen blanking
    xprintidle tracks all X11 input including mouse motion, which never
    reaches the idle threshold on a boat — the wireless mouse receiver
    picks up vibration and continuously resets the timer. Switch to
    monitoring the keyboard input device directly via dd+timeout on
    /dev/input, ignoring mouse events entirely. Also add navigator to
    the 'input' group for device access.
2026-06-26 autopilot_pi: add docked layouts for right and top/bottom panes
    Replaces the single fixed-pixel 3-column float layout with three
    mode-aware layouts that rebuild automatically when the AUI pane is
    docked or undocked:
    - FLOAT: original 480px 3-column grid, unchanged
    - RIGHT: single-column stack (col1→col2→col3) at 100px, with compact
    box heights, 1px interior padding, and touch-friendly 38px buttons
    labelled <, >, <<, >> for heading adjust and WP for waypoint send
    - TOP_BOTTOM: all boxes in one horizontal row stretching full chart
    width, controls row below; boxes auto-size to fit the pane
    Dock detection hooks wxEVT_AUI_RENDER directly so layout switches
    immediately when the user dr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
2026-06-26 autopilot_pi: add PinButton for title-bar undock on Windows/macOS
    Renders as a pushpin icon next to the close button on Windows and
    macOS, allowing undock from the title bar without using the in-panel
    Undock button. Silently ignored by the Linux/GTK dock art.
2026-06-27 addig Wire Contract
2026-06-27 autopilot_pi: step 1c — NMEA serialize/parse + ~APTX/~APRX plumbing
    Implements the §1c wire-contract work on the Navigator side:
    Serialize (outbound):
    - NmeaXorChecksum, FormatWPL, FormatRTE, MakeShortId build standards-
    compliant $GPWPL and $GPRTE sentences with XOR checksums and ≤6-char
    deterministic waypoint IDs, splitting RTE at 8 names/message.
    - SendNmea() wraps any NMEA line as ~APTX,<line>$ and unicasts to the
    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
2026-06-28 navigator: force 1280x720 at kernel level via video= cmdline parameter
    The XFCE/xrandr-level fixes (displays.xml + autostart) weren't durable
    because the vc4-kms-v3d driver (with disable_fw_kms_setup=1) negotiates
    the display mode directly from EDID before X11 starts, and the monitor's
    EDID-preferred mode is 1152x864. Anything X11/XFCE does is downstream of
    that negotiation and can be reset by any display rescan.
    Adding video=HDMI-A-1:1280x720@60 to cmdline.txt tells the kernel KMS
    driver to lock the connector to 1280x720@60Hz at boot, before X11 or
    XFCE run. The DRM connector name HDMI-A-1 confirmed via
    /sys/class/drm/card1-HDMI-A-1.
    The XFCE autostart xrandr and displays.xml fixes from t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
2026-06-29 adding changes to openCPN which I accidentally made on the mac, as well as fixes to circuit and the emulator code.
    [PCB_AP-Controller.dxf, PCB_AP-Controller_Autorouter.dsn, SCH_AP-Controller_Sheet_1_Altium.schdoc]
2026-06-29 fixing telnet ? command
    [telnet.ino]
2026-07-03 addiing Phase C to de-dupe route
2026-07-30 adding rudder and better display
2026-07-30 add rudder angle and ability to zero teh rudde
2026-08-02 adding rudder code and wind CAD files
    [BottomBearingHolder.FCStd, BottomHousing.FCStd, CupPointed.FCStd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]
2026-08-03 adding wind sensor sketch (untested since I have no board or wind vane)
2026-08-11 adding new auto-exported circiuits and modified sketches
    [PCB_AP-Button-LED-V2.dxf, PCB_AP-Button-LED-V2_Autorouter.dsn, PCB_AP-Controller.dxf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]
2026-08-12 movig board descrition to each dir
2026-08-23 adding cad cleanup
    [69915K52_Plastic Submersible Cord Grip.STEP, BackstayBase.FCStd, BackstayClamp.FCStd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]
2026-08-23 removing cad/tmp
    [69915K52_Plastic Submersible Cord Grip.STEP, CordGripBody.FCStd, CordGripNut.FCStd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]
2026-08-24 fixing common
    [BackstayClamp.FCStd, CordGripBody.FCStd, CordGripNut.FCStd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]
2026-08-25 fixing backstay base and README
    [BackstayBase.FCStd, BackstayClamp.FCStd]
2026-09-06 Fixing Wind and adding Wind to all things
    [TopCover.FCStd]
2026-09-08 adding wind-display and fixes for it to controller
    [AutoPilot.cpp, AutoPilot.h, dial.ino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]
2026-09-08 adding Settings to the plugin to calibrate rudder and wind
2026-09-09 adding roadtest instructions and increasing the APDAT frequency to 5Hz
2026-09-09 adding rudder to the apdat -> nmea bridge for rudder dashboard
2026-09-16 Making Display have a baklight button
